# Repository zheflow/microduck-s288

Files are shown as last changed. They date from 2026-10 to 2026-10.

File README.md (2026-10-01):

# microduck-s288

[English](README_EN.md) · 中文

用宇树 **S288** 舵机复刻 Pollen Robotics 的开源双足小鸭 [Microduck](https://github.com/pollen-robotics/microduck)。

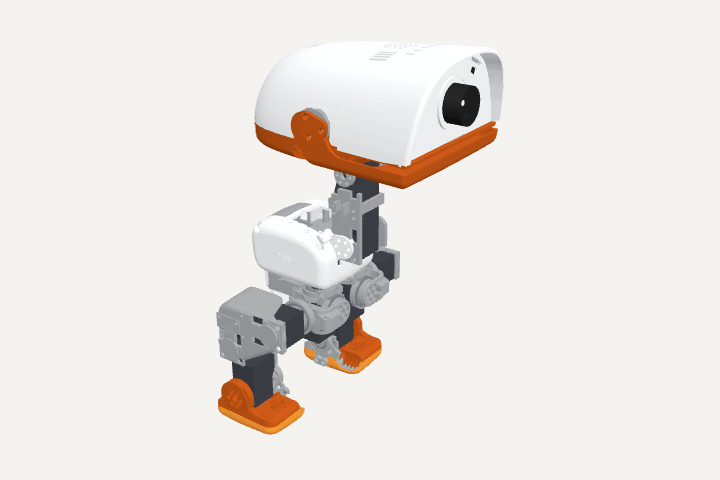
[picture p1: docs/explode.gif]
零件爆炸：散开 / 聚合


<sub>打印件 · 舵机 · 轴承，按子总成散开再聚合。交互版（可拖动旋转）：[docs/explode.html](docs/explode.html)，下载后用浏览器打开。</sub>

> **状态（2026-10-01）：打印件已发打印店，整机还没装起来。** 本次把 **CAD 生成源码、Gate 检查体系和全部设计数据**放出来了（见下"仓库目录"）。
> Gate 还没全绿：剩下的红主要是等实物才能登记的项（起子杆长、坐面、元件质量）和原版同类的碰撞对。
> **请先不要按现在的内容去打印或采购**，STL、清单、装配顺序等整机装起来能站住后再上传（见"路线"）。

---

## 为什么要复刻

原版 Microduck 的仿真模型、训练代码和策略都开源了，但 **CAD 不公开**，用的 Dynamixel XL330 舵机在国内也不好买。
所以这个项目：

- **借**原版的仿真骨架与策略：14 条关节轴线一根不动，原版训练好的走路 / 起立 / 坐站策略作为能力基线；
- **重做**全部结构件：按宇树 S288（塑料齿、塑料壳、Ø10.5 分度圆、实测堵转 0.66 N·m）重新画可打印的结构，
  头壳、髋、偏航件、躯干壳等件在原版网格的毛坯上切削改造；头为了装下主控、摄像头和喇叭每侧放大了 10 mm；
- **重训**：结构和电机都变了，策略要在按我们 CAD 生成的仿真模型上重新训练，不迁就原版限位。

## 选型（已定案）

| 部件 | 型号 | 备注 |
|---|---|---|
| 舵机 | 宇树 S288 × 15 | 含嘴；总线 1 进 5 个一分二，分 6 条串联链；插座在背面两角、沿轴向背插（实物核过） |
| 主控 | Radxa ZERO 3W | 装在头里；摄像头、NPU、USB 直连已在板上跑通 |
| IMU | Adafruit 4438（LSM6DSOX，STEMMA QT） | 躯干前壁，I²C |
| 摄像头 | Radxa Camera 8M 219（IMX219） | 脸板 |
| 测距 | VL53L5CX 多区 ToF | 脸板，避障用 |
| 电池 | 3S 1100 mAh 30C，XT30 | 躯干后仓，后门推入；不用时拔插头 |
| 供电 | 12 V 直供舵机总线；UBEC 5 V/3 A 给主控 | |
| 材料 | PLA 为主；发热处（头支架、头壳、功放 / 转接板托板）PETG；脚底 TPU | |

## 仓库目录

```
docs/explode.gif, docs/explode.html   零件爆炸动画（首页那张）与交互版
docs/gate/                            Gate 体系的校验记录与独立审计
duckstructure/                        整鸭 CAD 参数化生成（Python：trimesh + manifold），按身体部位分文件；data/ 是让位区域网格与头放大缓存
tools/cad/                            装配 / 机械审计、孔与清理检查等（build 和 Gate 共用）
tools/gate/                           Gate 8 层检查：gate.py 入口、layers/ 各层、data/ 设计数据 yaml、negatives/ 反例回归、slicing/ 切片检查
tools/sim/                            MJCF 生成、原版策略真实姿态采样、运动守卫
scripts/fetch_upstream.sh             拉取 Pollen 上游仓库到 upstream/（本仓库不分发它们的文件）
requirements.txt                      依赖版本
```

**Gate 的八层**：L0 网格合法性 → L1 可打印性（真切片）→ L2 特征是否真的切出来 → L3 零位干涉 → L4 装配路径与起子可达 →
L5 螺丝咬入与坐面 → L6 全行程与真实姿态碰撞 → L7 质量与扭矩。每层的判据只写不变量，红绿逐条留证据和出处；
`negatives/` 是反例包，每条判据都有"故意做坏的件必须变红"的回归，改判据先过反例。细节见 [tools/gate/README.md](tools/gate/README.md)。

### 怎么跑

```bash
python3 -m venv .venv && .venv/bin/pip install -r requirements.txt
scripts/fetch_upstream.sh                      # 上游仿真骨架与策略
.venv/bin/python -m duckstructure.build        # 生成 cad/duck_s288/（含 placed/ 装配位网格；十几分钟，吃内存）
.venv/bin/python tools/gate/gate.py            # 全量 Gate，结果在 tools/gate/out/（反例包约 7 min，各层另计）
```

L1 真切片要本机装 PrusaSlicer（`tools/gate/slicing/slice_l1.py --exe` 指定路径），没装时该层标 unknown，不冒充绿。

## 现在到哪一步了

- **CAD**：37 种 / 46 件打印件，全部参数化生成，改一个尺寸整鸭重出；第 8 版打印包已发打印店（左脚先试打）。
- **Gate**：全链能跑通，当前仍有数百条红——多数是"等实物才能填"的登记项（起子杆长、坐面、元件实测质量）和原版同类的碰撞对，
  每条都在 scorecard 里带出处。
- **仿真 / 训练**：按我们 CAD 重生成 MuJoCo 模型；走路 / 起立 / 坐站三个策略已在仿真里训过一轮；头比训练时重，正在做重量极限测试。
- **实物**：舵机、主控、摄像头、IMU、电池到手；主控板烧卡、联网、摄像头、NPU 推理跑通；板端运行时只做到读传感器，还没上力；**整机未装**。

## 路线（上传节奏跟着这个走）

1. ☑ 说明 + 许可证
2. ☑ CAD 源码、Gate 体系与设计数据（本次；Gate 全绿和独立复审在实物装起来的过程中补齐）
3. ☐ 打印件实物装机、能站住 → 上传 STL、打印清单、采购清单、装配顺序
4. ☐ 策略重训完成、实物能走 → 上传仿真场景、权重、训练配置
5. ☐ 主控端运行时（IMU、总线驱动、策略推理）

## 许可证

- **代码**（`duckstructure/*.py`、`tools/`、`scripts/`）：[Apache License 2.0](LICENSE)
- **硬件 / 3D 模型与设计数据**（`duckstructure/data/`、`tools/gate/data/`、`docs/` 里的网格与渲染）：[CC BY-NC-SA 4.0](LICENSE-HARDWARE.md) ——
  原版模型是 CC BY-SA-NC，我们的件是它的衍生作品，**不得商用**，再分发须署名 Pollen Robotics。
- 来源与致谢见 [NOTICE.md](NOTICE.md)。宇树 S288 手册受版权保护，本仓库不分发。

## 联系

Issue 区。项目还在早期，欢迎提问，但请理解"还不能装"这个前提。

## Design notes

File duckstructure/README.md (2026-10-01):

# duckstructure —— S288 版 Microduck 整鸭 CAD（按身体部位组织）

原来的 `tools/cad/duck.py`（1122 行单文件）按身体部位拆成了这个包。**纯搬运重构**：几何、常量、阈值、采样数、注释一字未改，
拆前/拆后 17 个 STL 的 sha256 完全一致、两个 json 去掉时间字段后相同、退出码相同。`tools/cad/s288.py`、`tools/cad/duck_kin.py` 也搬了进来
（`s288.py` 原样，`duck_kin.py` 改名 `kin.py`）。

## 怎么跑

```bash
# 在仓库根目录；一次只跑一个（4~6 分钟、吃内存）
./.venv/bin/python -m duckstructure.build
```

等价于原来的 `python tools/cad/duck.py`：导出 17 个 STL 到 `cad/duck_s288/`，跑零位干涉 + 逐关节扫掠 + 装配/机械审计，
写 `audit_summary.json` / `mechanical_audit.json`，`local/ placed/ scene_*/ xx/` 一并重出；有干涉或未闭环接口时退出码 **2**（当前预期就是 2）。

快速子集检查仍是 `./.venv/bin/python tools/cad/qcheck.py head|trunk|all`，装配抽出检查 `tools/cad/asmcheck.py`。

```python
import duckstructure as D          # 所有公开名字都从包顶层可拿：D.P / D.sfw / D.build_trunk / D.run_checks …
D.PARTS                            # 件号 → (STL 文件名, 导出用 MJCF 连杆, build 函数)，顺序 = 导出顺序
meshes = D.build_all()             # {件号: 世界坐标网格}，只建不导出不检查
```

## 改几何只改这里

| 想改什么 | 改哪 |
|---|---|
| 舵机尺寸（标 `[量]` 的实测值） | `s288.py` 里的 `S` |
| 关节轴线 / 舵机位姿 | **不要改** —— `kin.py` 从 `upstream/microduck_rl/.../robot_walk.xml` 读，是训练好的策略骨架 |
| 参数表 `P`、轴承/背板/踝副轴常量、电池仓位置（`BX0/BX1/BZ0/BZ1/RAIL_Y…`）、壳安装柱 `SHELL_BOSS`、`SERVO_SHIFT` | `lib.py` 顶部（冻结项，动之前先看 `docs/`） |
| 某一个件的形状 | 对应部位模块里的 `build_*`（下表） |
| 检查阈值 / 扫掠范围 `SWEEP` / 旧检查域 `LEGACY_LIMITS` | `checks.py` |
| 导出顺序、哪些原版件参检、场景导出 | `build.py` |

## 17 件一览

| 件号 | STL | build 函数 | 模块 | 装什么 | 依赖哪些别的件 |
|---|---|---|---|---|---|
| L01 | `L01_yaw2roll.stl` | `build_yaw2roll()` | legs | 髋偏航从动盘 + 髋横滚舵机载体（照原版 yaw2roll 重雕） | L02（左右髋件绕横滚/偏航轴扫掠让位） |
| L02 | `L02_hip.stl` | `build_hip()` @memo | legs | 纯双从动盘：一面髋横滚、一面髋俯仰 | — |
| L03 | `L03_upper_leg.stl` | `build_upper_leg()` @memo | legs | 大腿：髋俯仰 + 膝两颗舵机的等厚背板 + 膝 6704 座 | — |
| L04 | `L04_lower_leg.stl` | `build_lower_leg()` @memo | legs | 小腿：膝从动盘 + 踝舵机背板 + Ø9.95 踝副轴颈 | L03（膝反向扫掠）、电池实体（髋偏航扫掠） |
| L05 | `L05_ankle_foot.stl` | `build_ankle_foot()[0]` ← `build_ankle_parts()` @memo | legs | 踝主脚（法兰侧从动盘 + 脚板） | L04（踝反向扫掠 ±`ANK_SWEEP`）；`tools/cad/ankle_split.py` 分体 |
| L06 | `L06_sole_TPU.stl` | `build_ankle_foot()[1]` | legs | TPU 鞋底（原版 sole 减去 L05/L07） | L05/L07 |
| L07 | `L07_ankle_rear_arm.stl` | `build_ankle_rear_arm()` | legs | 可拆后轴承臂（6700ZZ 座，M2×12 接 L05） | 同 L05 |
| T01 | `T01_trunk.stl` | `build_trunk()` | trunk | 躯干：两个髋偏航载体 + 顶板 + 颈俯仰轭 + 电池仓 + 原版腹面甲板 + 壳柱 | 原版 left/right_shell（当刀）；`battery_bay()` |
| B01 | `B01_battery_door.stl` | `build_battery_door()` | trunk | 电池仓门（底脚 + 卡珠槽 + 2×M2） | — |
| T02 | `T02_shell_L.stl` | `build_trunk_shell(+1, trunk)` | trunk | 左躯干壳（原版外形，挖脖子活动空间 + 2 个 Ø2.4 孔） | T01（颈部区让位）、N01+N02（`neck_swing_env`） |
| T03 | `T03_shell_R.stl` | `build_trunk_shell(-1, trunk)` | trunk | 右躯干壳 | 同 T02 |
| N01 | `N01_neck.stl` | `build_neck()` @memo | neck | 脖子：颈俯仰 + 头俯仰两颗舵机背靠背的载体 | N02（头俯仰 ±45° 扫掠） |
| N02 | `N02_neck_pitch.stl` | `build_neck_pitch()` @memo | neck | 颈俯仰件（U 形轭 + 偏航立筒，照原版重雕） | — |
| N03 | `N03_yaw_roll.stl` | `build_yrm()` | neck | 偏航-横滚件（A/B 座盘 + 等厚背板 + 裙墙） | — |
| H01 | `H01_head_bracket.stl` | `build_head_bracket()` | head | 头内支架（原版 motor_support 毛坯 + 横滚舵机笼 + 香橙派立柱） | N03（横滚 ±25° 扫掠） |
| H02 | `H02_head_clamp.stl` | `build_head_clamp()` | head | 可拆压板（两根垫柱压横滚舵机背孔，两颗 M2×10 接 H01） | — |
| H03 | `H03_head_bottom_shell.stl` | `build_head_bottom_shell()` | head | 原版下头壳的 S288 适配件（只挖舵机让位） | — |

右腿 5 件不单独建：`build.py` 用 `mirror_y()` 镜像左腿参检（`MIRROR` 表给出镜像后的 MJCF 连杆名）。

`@memo`（`lib.py`）：同一进程内同名 build 函数只算一次，结果放在 `lib._MEMO`。L01 里扫 L02、L04 里扫 L03、L05 里扫 L04、
N01 里扫 N02、T02/T03 里建 N01/N02 都走这个缓存，所以谁先建都不会重复算。

## 模块与依赖

```
s288 ───┐
kin  ───┼──▶ lib ──┬──▶ legs ──────────────────────┐
                   ├──▶ neck ──┬──▶ trunk ─────────┤
                   │           └──▶ head ──────────┼──▶ build（入口）
                   └──▶ checks ────────────────────┘
                                   __init__ 再导出以上全部公开名字，给 build.py / tools/cad 的检查脚本当"duck 模块"用
```

| 模块 | 放什么 | 行数 |
|---|---|---|
| `s288.py` | S288 舵机参数表 `S` 与舵机坐标系原语（`cyl/bx/union/diff/inter/placed/frame/servo_envelope/servo_mesh/horn_holes/mount_holes…`） | 166 |
| `kin.py` | 读 MJCF `robot_walk.xml`：`load()` → `B, ORDER`（连杆树、关节、舵机位姿、原版网格）；`mesh(name)` | 62 |
| `lib.py` | `OUT`、`B/ORDER`、参数表 `P`、全部全局常量（`XR/PLT/RING_T/ANK_*/电池仓/RINGS/SHELL_*/SERVO_SHIFT/XLF`）、`memo`、世界/舵机坐标工具（`TW/orig/sfw/drv_from/drv_self/pt/servo_env/to_local/mirror_y/MIRROR`）、舵机坐标原语（`carrier/spacer_card/card_cut/mount_cut/driven/driven_patch/horn_cut/horn_cbore/flange_relief/flange_slot/mnt_cut2/back_pad/back_shell/wide_y/brg_ring/ring_boss/bearing_driven_clearance/servo_slide`）、通用几何（`hull/wbox/ybox/fill_cyl/silhouette/sweep_of/keep_main/minkowski_box/clean_print_topology/stl_stats`）、原版壳（`shell/shell_inner_z/shell_cutter`） | 448 |
| `legs.py` | L01–L07 | 124 |
| `neck.py` | N01–N03 及其局部常量（`NK_*/NP_*/YRM_*`） | 132 |
| `trunk.py` | 电池仓（`battery_bay/battery_bay_cuts`，仓门/底脚/卡珠常量 `FOOT_*/DOOR_SCREW_X/SNAP_*`）、B01、`DECK_TOP`、T01、`neck_swing_env`、T02/T03 | 158 |
| `head.py` | `HEAD_CLAMP_MOUNTS`、H01–H03 | 88 |
| `checks.py` | `check_angles`、`EXPORT_STATS/export`（STL 闭合/单实体断言）、`vol`、`descendants`、`LEGACY_LIMITS`、`SWEEP`、`run_checks`（零位干涉 + 逐关节扫掠） | 109 |
| `__init__.py` | 再导出各子模块的公开名字、`PARTS`（件号→build 函数的有序表）、`build_all()`；把 `tools/cad/` 塞进 `sys.path` | 57 |
| `build.py` | 原 `duck.py` 的 `__main__` 原样：建 17 件 → 镜像右腿 → 原版头壳/舵机/轴承参检 → `run_checks` → `mechanical_audit.verify_mechanics` → 写两个 json → `local/ scene_*/ placed/ assembly_preview.stl` → `sys.exit(2)` | 111 |

归属原则：被谁用就放谁那，多处共用放 `lib.py`。和"部位"直觉不一致的几处：

- **电池仓位置常量**（`BAT_CLR/BX0/BX1/BZ0/BZ1/BAT_Y/RAIL_Y/RAIL_Z0/DOOR_*/BAY_FW/BRACE_Z/BZR0/BZR1`）在 `lib.py` 而不是 `trunk.py`：
  L04 小腿要拿电池实体绕髋偏航扫掠削让位，`build.py`/`qcheck.py` 也要放电池实体参检。仓门自己的常量（`FOOT_*/DOOR_SCREW_X/SNAP_*`）留在 `trunk.py`。
- `neck_swing_env()` 在 `trunk.py`：它建的是脖子的扫掠包络，但只有躯干壳用它挖料。
- `ybox()`、`mirror_y()/to_local()/MIRROR` 在 `lib.py`：L01 要镜像对侧髋件，`build.py`/`qcheck.py` 要镜像整条右腿。
- `check_angles()` 只被 `run_checks` 用，放 `checks.py`。

## 与 tools/cad/ 检查脚本的关系

`tools/cad/{assembly_audit,mechanical_audit,ankle_split,asmcheck,qcheck}.py` 留在原地，改成从 `duckstructure` 导入。
`assembly_audit.bearing_specs(D)` / `mechanical_audit.verify_mechanics(D, allm)` 需要一个带 `B/sfw/TW/cyl/vol/placed/s288/orig/inter/diff/…` 属性的"duck 模块"，
`build.py` 传的是 `duckstructure` 包本身（原来是 `sys.modules[__name__]`）。

包里保留了原文的三处**函数内延迟 import**（`lib.minkowski_box/clean_print_topology` → `assembly_audit.solid`，`legs.build_ankle_parts` → `ankle_split.split_ankle`），
它们 import 的是 `tools/cad/` 的顶层模块而不是包内模块，本身没有循环；`__init__.py` 把 `tools/cad/` 塞进 `sys.path`（原 `duck.py` 第 7 行的等价物）。
包内模块之间没有循环依赖，模块划分本身就是无环的 —— 没有任何一处包内依赖是靠函数内 import 掩盖的（上面三处延迟 import 指向的都是包外的 `tools/cad/` 脚本，原文就这么写）。

## 拆分时唯一改过的三处（都不是几何）

1. `lib.py`：`OUT = …("..", "cad", "duck_s288")`——原来是 `("..", "..", …)`，因为文件从 `tools/cad/` 上移了一层。`kin.py` 里 `MD` 同理少一个 `".."`。
2. `build.py`：`bearing_specs(sys.modules[__name__])` → `bearing_specs(D)`；`verify_mechanics(sys.modules[__name__], allm)` → `verify_mechanics(D, allm)`，`D` 即 `duckstructure` 包。

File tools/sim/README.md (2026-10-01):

# 本地策略回放的 CAD 预检

`render_policy.py` 现在在写入 `data.ctrl` 前执行强制预检。预检拒绝时退出 **2**，保留 JSON 中的关节、姿态、路径比例、相交零件和 mm³；不会把目标逐轴夹角后继续运行，也没有跳过预检的命令行选项。

从仓库根目录用 `./.venv/bin/python`：

```sh
# 仅在完整 CAD 构建结束、STL 稳定后记录源身份。这个操作不表示几何通过。
./.venv/bin/python tools/sim/cad_motion_check.py snapshot

# 真实回放入口，所有输出检查在本机执行，不打开串口。
./.venv/bin/python tools/sim/render_policy.py \
  sim/runs/2026-09-06_baseline_xl330/baseline_xl330.onnx \
  sim/guarded_policy.mp4 --seconds 5 --no-video \
  --report docs/repair_2026-09-09/motion/replay_preflight.json

# 也可以先检查已记录的目标序列；遇到第一处问题停止。
./.venv/bin/python tools/sim/cad_motion_check.py trajectory \
  docs/six_checks_2026-09-08/policy/forward.npz \
  --report docs/repair_2026-09-09/motion/forward_preflight.json

# 轻量回归，不创建真实 CAD、不操作硬件。
./.venv/bin/python -m unittest discover -s tools/sim -p test_motion_guard.py -v
```

实际生效的检查：

- 关节顺序和全部 14 个关节范围直接读 `robot_walk.xml`；不使用旧 CAD 窄窗口。目标、当前姿态和上次目标必须全维、有限且符合范围。右髋横滚的 23.093° 目标会被拒绝，MJCF 上限为 22°。
- 用 `placed` 世界零位网格和完整运动学链做联合姿态布尔检查，阈值保持 **0.05 mm³**。该阈值只是数值检查阈值，不是可以接受的物理干涉。
- 每次提交检查“当前姿态→目标”和“上次目标→新目标”两条关节线性过渡；最大单关节采样间距 **0.5°**，短移动也检查中点。每个 MuJoCo 物理步后还检查观测姿态间过渡，发现偏离造成的冲突则停止后续积分。
- 固定在同一刚体内的适配件也在启动时检查。剩余三个原版头部原件之间的 3 个配对沿用主 CAD 明示排除范围。H03只对上头壳保留一个额外白名单：每次加载都从原版下头壳计算原始交集，确认 H03 的交集没有超出原始接合区（数值误差阈值0.001 mm³）。H03与舵机、支架、脸件和下颚等其他配对正常检查；白名单与原版对比数字写入报告。
- `cad_geometry_manifest.json` 绑定完整对象清单及 STL、运动学和相关源码的 SHA256。缺件、多件、源散列不符、运行中源文件改动、布尔异常或无效结果均拒绝。运行时检查文件的 inode、大小、mtime、ctime；重新启动时完整核对散列。缓存不能绕过源变化检查。

`MotionGuard.apply_target()` 是可复用入口，但它只实现离线的预检。回放明确选用 **scene_walk.xml→robot_walk.xml**，与六项补查的基线一致；原入口所用的 `scene.xml→robot_allcollisions.xml` 不再被间接默认选择。物理步长0.005 s、implicitfast、10次接触求解迭代都写入报告。它仍是 **原 XL330 XML 执行器动力学**，没有添加 S288 整机驱动，也没有声称已接入实机。拒绝意味着停止离线回放，不能把这个处理直接移植成运动中的实机急停策略。

采样通过仅证明已取样姿态没有超过阈值的相交：它不证明连续时间无碰撞、任意执行器异步响应安全、制动可行、打印公差、轴承负载、线束或电路安全。模型有固定干涉时，正确行为是启动即拦截；源身份快照不是绕过这个拦截的许可。

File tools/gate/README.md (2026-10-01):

# Gate —— 可打印 / 可装配评价体系（规格）

> 目标：**换件（摄像头、麦克风、头壳……）之后不改检查器，还能查对。**
> 做法：检查规则只写**不变量**，不含任何具体零件的具体坐标；一切"应该是什么"都在 `data/` 里声明，换件只改数据。

状态：规格阶段。元件库与三份清单正在从原版 + V2 盘点生成（见 `docs/gate/inventory_*.{json,md}`）。

---

## 1. 数据（`tools/gate/data/`）—— 换件只改这里

| 文件 | 内容 | 一条记录长什么样 |
|---|---|---|
| `components.yaml` | **元件库**：每个外购件一条 | envelope / mount 孔阵 / connectors(位置·插头实体·拔插方向·线出口) / cable(根数·径·最小弯折半径·长度) / keepout(视锥·声孔·气路) / mass·com / power·heat / insert_dir / **每个字段标 measured\|datasheet\|assumed** |
| `parts.yaml` | 17 个打印件 | 由哪个 build 函数出、材料、打印朝向、镜像关系、houses(装了哪些元件) |
| `features.yaml` | **特征清单** | 每个孔/沉头/槽/凸台/夹持面：件、种类、名义尺寸、深度、通盲、方向、作用（固定谁）、连接类型 |
| `fasteners.yaml` | 每颗螺丝 | 规格、长度、连什么和什么、拧进什么材料、**它自己的刀具包络**（Ø4/Ø5/PH0…）、驱动方向 |
| `assembly.yaml` | **装配顺序清单** | 逐步：动哪个件、沿什么方向/路径、此时已装了什么、用什么工具；拆卸序也写 |
| `relations.yaml` | **功能关系清单** | 夹持/压配/滑配/轴承座/舵盘耦合/从动盘/铰链：谁和谁、目标量（过盈·间隙·同心）、依据（实测试件 or 占位） |
| `keepouts.yaml` | 禁入体 | 视锥、声孔、舵盘摆动扇区、电池抽出路径、SD/USB/开关/充电口、刀路、线束弯折空间 |
| `harness.yaml` | 线束路径 | 每束：折线 + 直径 + 最小弯折半径 + 两端插头 + 长度预算 + 跨哪个关节 |
| `frozen.yaml` | 不许动的 + **能力包络** | 关节轴线、电池仓 26 项、SHELL_BOSS、立柱、6 个原版 STL、**躯干 IMU 位姿**；`capability_envelope`（2026-09-16）：原版策略在 in-scope 任务模式下实际用到的关节角（来源 policy_envelope.json、左右镜像求并、margin），`joint_axes[].target_range_deg` 由 `derive_target_ranges.py` 从它推导——**判据来自原版能力，件去满足它**，不按件能转多少填 |
| `tolerances.yaml` | 公差表 | 按 **材料 × 打印方向 × 特征类型** 存；未实测的填占位值并标 `assumed`。**连接类型决定咬入范围**：S288 金属螺纹 1.8~3.0 / PLA 自攻 ≥2×d / 热熔螺母按螺母长 |
| `waivers.yaml` | 豁免 | 格子 id、理由、签发人、日期、**绑定的输入 hash**（输入一变自动失效） |
| `bench.yaml` | 实机验证清单 | 只能实测的判据（预紧变形、温升、掉线行为、疲劳…），现在写死数字，到货逐项打勾 |

---

## 2. 层（每层一句话判据，全部 mm / mm³，不四舍五入，未知 = 失败）

| 层 | 问 | 判据 | 数据来源 |
|---|---|---|---|
| **0 网格与坐标** | 是合法实体、在对的坐标系里吗 | 洞边=0 · 实体=1 · 退化面=0 · 非流形边=0 · **基准特征（舵盘轴心）落在 MJCF 位置 ±0.05** · 包围盒在预期范围（抓米/毫米、Y-up、未 apply transform） | parts / frozen |
| **1 可打印** | 打印机吐得出来吗 | 真切片：最薄壁 ≥2 圈 · 最小孔 ≥2×喷嘴 · 悬垂 >55° 的面在支撑可拆区 · **支撑落点按真 G-code**：forbid 区（轴承座/轴颈/锪平/走廊配合面壳层）= 0 点 BLOCK、removable 区 WARN + 后处理 · TPU 单独规则 | parts(朝向·材料) + printability(parts/no_support_zones) + tolerances |
| **2 特征存在** | 声明的孔/台/槽真的在吗 | 逐条：射线验通/盲深 ±0.1 · 直径 ±0.1 · 沉头 · 孔周壁厚 ≥ 阈值 · **镜像件特征镜像误差 <0.05** | features |
| **3 静态装配** | 零位姿各就各位吗 | 打印件 × 打印件、打印件 × **元件完整实体**（placed 占位体 + `envelope_solid` 独立实体两份）、× **禁入体**（几何/豁免全在 keepouts.yaml，KO01 不借 CAD 切刀）：交集 < 0.05 mm³ · **冻结项实测**（电池仓 26 项 / H01 立柱 / IMU 安装孔 ±0.1） | components / keepouts / frozen / fasteners ；**hr50（09-28）**：`frozen.yaml:battery_bay_26.door_plate_retired{probes,date,decided_by,regression_now}` 列出的门板侧探针（DOOR_T / BX0 / DOOR_YLO…）照量照记数字但发 RETIRED（用户 09-22 解冻电池仓+门、hr48 有意改门；回归转 L2 B01-F01）；非门板探针名 / 缺字段 → unknown 且不退役 |
| **4 装得进去** | 每个东西有路进到位吗 | 按 assembly.yaml 逐步：移动件沿路径扫掠 vs 已装件 = 0 · 每颗螺丝按**自己的**刀具包络有直线通道 · 螺丝头沿刀轴可见 · 拆序也通 | assembly / fasteners |
| **5 功能达成** | 装上后它干活吗 | 夹持过盈 · 卡扣咬合深 · **咬入按连接类型** · 螺丝总长 ≤ 叠厚+盲深−0.3 · 轴承配合按公差表 · 舵盘 6 孔同心 <0.05 · **舵盘时钟**（零位下孔阵相位 = 声明值，抓 60° 倍数错位）| relations / fasteners / tolerances |
| **6 运动** | 动起来撞不撞卡不卡、**原版能做的姿态我们做不做得出** | 单轴 2.5° 独立网格 + **相邻关节两两组合 5° 统一网格**；碰撞在 `frozen.yaml:target_range_deg`（由能力包络推导）内 BLOCK、外 WARN（工作空间比原版窄但原版任务用不到）；**能力判据** `_capability/*`：每个 in-scope mode 的包络 ± margin ⊆ 本层量出的无碰撞区间（BLOCK）、**原版策略真实姿态**（`policy_envelope.py --dump-steps` 逐步元组 → `policy_pose_collisions.py` 离线布尔 → `policy_pose_compare.py` 与原版全件同姿态逐 body 对比，summary/compare 双指纹核对）**hr50（09-28 用户定：极限姿势靠重训限制、不削）起按 `tools/gate/data/real_pose_policy.yaml` 判**：极限段（alpha_stand/body_all_max、roulade、alpha_sitstand/head_all_min）里的碰撞不阻断，逐对列进 `real_pose_retrain_constraints`（INFO：件对、姿态数、最大交集、最大那帧穿插深度、到头的关节）；其余姿态交集 ≤2.2868 mm³ 且穿插深度 ≤0.7696 mm（原版自身真接触峰值 p25，hr50 C 标定）为轻碰，超出或深度算不出 → `real_pose_collisions` BLOCK；原版共有碰撞仍不豁免；**相邻两关节组合 `pair_combination`（hr50 v3，09-28 用户定，同一 yaml 的 `pair_combination` 段）**：碰撞记录逐条分类 —— 有一轴在目标区间外 → 工作空间 WARN（F-L6-3 不变）；区间内、网格姿态 ±5.5°（网格半步 2.5 + margin_deg 3）内原版策略逐步记录（`frozen.yaml:capability_envelope.pose_steps_source`，sha 校验，去掉三段极限段，按 mirror_pairs 左右镜像求并）从没到过 → 进 `pair_combination_retrain_constraints`（INFO：件对、最大交集、深度、撞点网格按连通块给耦合区间『q1、q2 不能同时进这个区间』，各向外扩一格）；到过 → 同上轻碰口径，超出 / 深度算不出 BLOCK；**v4（09-28 用户定）**：超轻碰但落在 `approved_retrain_constraints`（用户逐条批准的重训联动限位：件对 × 关节对 × 耦合盒 × 体积上限，上限 = 正式 chain 在冻结 STL 上量的数、不留余量）盒内且 ≤ 上限 → 不 FAIL、逐条列出，超上限 / 盒外照 BLOCK，登记了没命中的列 unused；重训约束另按关节对合并成训练用区间（`per_joint_pair`）；**v6（09-28 用户定 C）**：`_policy/policy_extreme_poses` 的策略包络角点姿态记录（每 mode 30 个 14 轴同时到包络角的姿态，不是可达集）也按同一口径逐条分类（『到过』= **全部 14 轴**同时 ±5.5° 内有原版样本），没到过 → `_policy/policy_extreme_poses_retrain_constraints`（INFO），只有『到过且超轻碰』BLOCK、只有区间外 WARN；件格子 / 汇总按 `pose_class` 同分类；口径段缺 → unknown；同一批记录在 `motion_collision` / `collision_buckets` 里也按这个分类，只有『到过且超轻碰』算件的问题；包络证据坏 / 分类失败 → unknown；能力盒内的碰撞只 WARN（轴对齐盒是上界，README A2）；生成 MJCF range ⊆ 无碰撞区间、⊇ 目标区间；运动对**最小距离 ≥ 公差表值**（豁免只认 relations 声明的 contact）；线束沿路径扫管过全行程 | frozen(capability_envelope, target_range_deg) / policy_envelope.json / relations(contact) / harness / tolerances |
| **7 质量与力** | 撑得住、站得稳吗 | 17 件体积×密度 + 元件实重（按 `components.yaml:claim` 认领）→ 每 body 质量重心 · **与 MJCF `<inertial>` 逐 body 比漂移** · 每关节扫描峰值与 home 姿态静扭矩 < S288 额定 × 系数 · 零位/home 重心投影在支撑多边形内 · **质量清单有缺口 → 整机判据 unknown（只给下界文本）** · 承力最小截面 / 薄筋长厚比 / 层向 vs 受力 | components(mass, claim) / parts(ground_contact) / frozen / tolerances(load) |

不进 Gate、进 `bench.yaml` 的：预紧变形与摩擦、多舵机峰值电流与压降、温升、掉线/重上电行为、线束疲劳、热管理、传感器实际可用性、耐久。

---

## 3. 元规则（保证"绿"是真绿）

1. **查最终导出的 STL 读回来的东西**，不查内存网格。送去打印的是文件。
2. **每个 0 带证据数量**：几对、几个角度、几条射线。`0 碰撞 / 0 对` = 没跑，不是通过。
3. **采样网格独立于建模角度**（`check_angles()`）。
4. **未知 = 失败**：布尔炸了、特征找不到、清单没写、字段是 `assumed` 而配合间隙 < 公差表值 → 都红。
5. **不变量，不比历史**：体积/交集与上一版的差异只做 WARN 级"变更告警"触发人看，**不是放行条件**。
6. **hash 绑定**：记分卡写入 `duck.py`、`s288.py`、`robot_walk.xml` 的 git hash + 17 个 STL 的 sha256 + `data/*.yaml` 的 sha256。hash 对不上的记分卡作废；发布副本 ≠ 源码直接红。
7. **过期标记**：每个格子记录输入 hash；输入变了格子变灰，不得沿用旧绿。改一个件只重跑受影响子集。
8. **反例回归包先跑**：`negatives/` 里每个历史事故一个坏样本（空刀、轴承截面、压板零间隙、扫掠区间反、螺丝加长 2 mm、删一个件、单位错成米…）。Gate 每次运行先证明自己**每个都能红**，否则 Gate 本身判失败。
9. **三级 + 豁免**：BLOCK / WARN / INFO。只有 WARN 可豁免，豁免绑定输入 hash，输入一变自动失效。
10. **性能**：内容 hash 缓存 · AABB / 采样距离粗筛后再精确布尔 · 单件检查可独立跑；整机全绿一次不应超过现在 `duck.py` 的一半时间。

### 3.1 元规则落地状态（2026-09-13 审计后第一批；每条修复都有反例）

| # | 状态 | 落在哪 | 反例 |
|---|---|---|---|
| 1 | 落实 | 各层读 `cad/duck_s288/*.stl` / `placed/*.stl` | n_l0_units_meters / n_l2_* |
| 2 | 落实 | `core.build_scorecard`：evidence_n=0 的 PASS → NOT_RUN | n_core_evidence |
| 3 | 落实 | `duckstructure/checks.py:check_angles` 零度对齐网格 | n_l6_reversed_range |
| 4 | 落实（框架级补丁） | 覆盖率义务在清单缺 id 时**写红格**而不是跳过（`core.py:COVERAGE_ITEMS` 循环） | n_core_coverage_no_id |
| 5 | 落实 | 层不读 prev；`impact.md` 只报变化 | — |
| 6 | 落实 | `gate.py --verify`：逐格 inputs_hash + source_manifest + git HEAD 与磁盘核对，不一致退出码 3 | n_core_verify |
| 7 | 落实 | 格级 inputs 隐含 `duckstructure/*.py`；`--layers/--parts` 子集跑写 `scorecard.partial.json`、不写 prev，范围外格子按 hash 继承 | n_core_partial_inherit |
| 8 | 落实（契约收紧） | 反例必须声明 `expect_severity` 且 `red` 里每条 measured 非 None（`negatives/runner.py:check_contract`）；结果按 `sha256(negatives+layers+core+gate+tool_access+slice_l1+data)` 缓存到 `out/negatives.cache.json` | 全部 n_* |
| 9 | 落实 | 豁免 id 必须带判据名；`bound_input_hashes` = {仓库相对路径: sha256}（`waivers.yaml:schema`） | n_core_waiver / n_core_waiver_cell_only |
| 10 | 部分 | 反例缓存命中 ≈ 0.03 s；层级结果缓存仍未做（全跑 ≈ 30 min；09-13 第二批后 L6 组合 5° 网格多 ≈5 min） | — |
| 4b | 落实（L5/L7） | **阈值也要有来源**：`fits.*.target_range_*` / `feature_check_tolerances.*` / L7 密度·稳定裕度·筋容差 节点无 `src` → 引用它的判据 unknown；`src=assumed` → 照判 + `threshold_assumed:<键>` FAIL(WARN)，measured=阈值本身（`l5_screwhead.threshold_meta / AssumedThresholds`，l5_function、l7_mass 同源） | n_l5_threshold_src、n_l7_generalized |
| 4c | 落实（gate_guard 09-25） | **层崩溃 / 层空跑不许静默**：层模块抛异常 / 层进程被杀、进程池断 / 返回不可解析 / import 失败 → `L<n>/_layer_error`（FAIL，BLOCK，`layer_crashed`）；全量跑时层模块 0 条判据 → 同格（`layer_zero_findings`），子集跑只打印提示；终端摘要顶部与记分卡 md 标题下各一行 ⚠，结论 BLOCKED、退出码 1（`gate.py:_layer_guard`；断池时 `_exit_after_main` 用 os._exit 收尾防解释器收尾挂死） | n_core_layer_error |
| 8b | 落实 | 反例缓存 key **静态全盖**（`tools/gate/**/*.py`、`duckstructure/*.py`、`tools/cad/*.py`、`data/*.yaml`、`slicing/*.yaml`、`l1_calibration.yaml`、标定网格）+ **运行时** `sys.modules` 仓库内模块清单 + trimesh/manifold3d/numpy/shapely/Python 版本；命中时 `L0/_negatives` 照写、标 `cached` | n_core_neg_cache_key |

状态语义：`STALE` = 输入变了没重跑（继承可恢复）；`RETIRED` = 判据基准失去权威、只留记录（不阻断、不计 INCOMPLETE、单独计数，`core.py:RETIRED`）。层里**不许**再硬编码 `state=STALE`。

### 3.2 本轮新增的写层约束（2026-09-13，各有反例）

| 约束 | 来源 | 反例 |
|---|---|---|
| **覆盖 = 量到，不是发过**：`res.covered` 只登记至少发出一条带 measured 判据的条目；只发 unknown 的不算覆盖 | F-L2-1 | n_l2_coverage_gap |
| **量的是零件不是三角化**：从网格取尺寸必须对分段数免疫（棱边/顶点法），射线内接径只作旁证；float32 表示噪声（≤1e-5）可吸收，阈值不动 | F-L2-2 | n_l2_facet_diameter |
| **"有实测撑着" = 实测通过了**：桶/汇总格只能引用 state==PASS 的实测判据；量了没过要传红，不传"已量" | F-L5-3 | n_l5_fit_measured_only_on_pass |
| **方向必须声明，不取较差端**：头侧、压紧方向只从 data 的显式字段取，取不到判 unknown；"两端取较差"是把对面的缺陷记到这一面 | F-L5-1/2 | n_l5_head_on_pilot_hole、n_l5_fg15 |
| **没评过 ≠ 没误伤**：标定/统计类判据分母只数真评过的（PASS 且 evidence_n=0 不算）；范围内任一 BLOCK 判据一次没评 → 标定不成立 | F-L1-1 | n_l1_calibration_record |
| **"每个"就写 `== len`**：criterion 写"每个"的判据不许用 `if n:` 判 | F-L7-2 | n_l7_inertia_tensor_all |
| **区间必须有序**：任何 [lo, hi] 声明 lo ≥ hi 一律 unknown，不许让采样函数退化成两端点 | N4 | n_l6_reversed_range |
| **反例先跑一次红**：新判据/修复先写反例并在改代码前跑出失败，再改 | 元规则 8 | 本轮全部 |
| L4 工位在场全集必须 ⊇ 从 `seq`/`subassembly_of`/`subassemblies` 推导的最小集合（`present_covers_derived` BLOCK）；反向顺序矛盾 `present_only_installed` WARN；`tool_states` 必须带 `after_step`/`side` | F-L4-1 | n_l4_present_derived |
| L4 轴承 token（6700/6702/6704/`22×16×4`）→ 外径按 `components.yaml` 解析，不写死 | F-L4-1 / §2.6 | n_l4_present_derived（'6704×2' 类 token 进 parts） |
| **禁入体不借 CAD 切刀**：KO01 插头顶/线弯区 A + 侧出线槽 B / 背板通窗 W 由 `keepouts.yaml:KO01.dims` + `availability_table.rows[].mode_*` 独立建（09-20 背插模型），舵机落位只借 `sfw`；CAD `conn_cut` 只作对照 INFO（`keepout_KO01_vs_cad_cutter`）；dims 缺 → unknown | F-L3-2 | n_l3_ko01_independent |
| **元件实体要有一份不与 CAD 同源的**：`components.yaml:envelope_solid`（ring/box/none）独立建实体、落位只借 placed 的 OBB；`placed_covers_envelope`（顶点法，对分段数免疫）+ `part_vs_component_envelope`；同源的 `part_vs_component_solid` criterion 写明"与 CAD 同源"；未声明 → unknown | F-L3-3 | n_l3_component_envelope |
| **冻结项要真核**：`frozen.yaml` 的 `battery_bay_26`（T01/B01 射线）、`h01_sbc_posts`（H01 截面闭环）、`imu_pose`（T01 射线扇 + 生成 MJCF site + delta 算术）按 `measured_on` 对导出件实测，阈值 `frozen_dimension_mm`；射线分不出的（卡珠埋在导轨里）判 unknown，不是导出件几何的逐条 INFO 登记 | F-数-1 | n_l3_frozen_items |
| **禁入体参数与豁免全在数据**：KO06 `servo_frame_of_joint`、KO07 `axis_joint`、KO11 `probe_zone_z_mm`、KO12 `exempt[]`、KO15 `fov_deg/apex_world_mm/optical_axis_world` —— 缺 → unknown，不再默认 `neck_pitch/head_yaw/100..175/"B01"/+x`；元件认领按 `components.yaml:claim`（与 L7 同一份声明） | §2.6（L3） | n_l3_keepout_data_driven |
| **扫掠/运动类禁入体的义务派给真查它的层**：`keepouts.yaml:KOxx.checked_in_layer` + `covered_by_subjects`；`core.obligations` 按它派层，`core.build_scorecard` 把所列格子汇总成 `L{层}/KOxx`（缺格 NOT_RUN、红传红），第 3 层只留 NOT_RUN INFO 留痕 | L3 MINOR（`_DEFERRED` 永久 INCOMPLETE） | n_core_keepout_layer_routing |
| **支撑落点按真 G-code**：解析 `;TYPE:Support material/interface` 挤出段 0.2 mm 采样、逆变换回 export_local、对 `no_support_zone_set` 逐区数点；两级 forbid（BLOCK）/ removable（WARN + 后处理进打印清单）；`per_feature_overrides` 可改级；zones_sha256 只带**本件**特征的 override，别件改 override 不作废本件记录 | F-L1-3 / C-10..13 | n_l1_support_landing_tiers、n_l1_support_in_bore/_box_zone |
| **切片配置不进代码**：逐件朝向 / 填充率 / 周界生成器 / 追加参数全在 `printability.yaml:parts.<件>`（`down_world` 等），缺 → `slice_l1.py` 退出不给缺省；`--parts` 子集重切沿用其余件记录 | §2.6（slice_l1） | —（脚本级，层由 slice_freshness/zones_sha256 兜住） |
| **刀心不是坐面**：`features.yaml:hole_positions_mm` / `feature_hole_map[].holes` 是切刀中点（常离件 15–19 mm 甚至在件外），只能当轴线锚；头/坐面判据的起点一律是 `fasteners.yaml:tool_access[].seats[].point_export_local`，头侧 = `outward_export_local`；坐面点到孔轴横向偏差 > 1e-6 → unknown（与 `tool_access.py` 同规则）；孔轴优先取特征声明轴（`geom.instances[k]` 按 `feature_hole_map[].instance` 取），实测轴起点在孔腔里、只作 `hole_axis_declared_vs_measured` 旁证 | F-L5-2 第二半 | n_l5_seat_origin_cutter_mid、n_l5_fg15（E：坐面点在料里 → unknown） |
| **匹配键带 instance**：`declared_head_sides` 键 = (feature_id, instance, map_index, hole_index)；左右实例（mirror_y，同一份 STL、export_local 同坐标）同 outward 不是冲突、几何量一次并记录覆盖的 instance；"冲突"只在同一 instance 同一孔给了不同 outward 时成立；某个 instance 缺坐面 = 那颗螺丝未声明 → unknown | F-L5-2 第二半 | n_l5_seat_instance_key |
| **头侧孔全集 = `head_locator_map_indices`**：同一颗螺丝的 counterbore / spot_face 条目不是另一颗螺丝，不进"未声明"计数，也不作为叠厚/坐面的测量孔；locators 缺/重复/越界 → `head_side` unknown | 主线程 09-13（F02/F03/F10 "6/12 未声明"真因） | n_l5_seat_instance_key、n_l5_seat_origin_cutter_mid |
| **头判据只看头高区**：从坐面点沿 outward 退 60 mm 向内打，每条射线只认坐面外侧 ≤ 头高（`frozen.yaml:P_dict.m<N>_head.h`）内的第一张进料面；更外侧的杯壁/另一堵墙不算坐面；头高区内无进料面 = 头下悬空；足印环带在坐面头侧 1e-3 mm 处全是料 = 坐面点在料里 → unknown（不报成悬空） | F-L5-2 第二半 | n_l5_fg15（C 远端台阶绿、E 料里 unknown）、n_l5_head_on_pilot_hole（悬空红） |
| **阈值 src 进判据**：criterion 写"阈值 src=measured/datasheet/assumed/缺"；无 src → unknown；assumed → 照判 + `threshold_assumed` WARN。`engagement_by_joint_type.*.range_mm`、`screw_length_rule.tip_margin_mm`、`hole_diameter_mm`（L5 只当关联容差）本轮**未**纳入 | F-L5-4 | n_l5_threshold_src |
| **结构化字段优先于自由文本，两者不一致 → unknown**：自攻盲深先读 `fasteners.yaml:<组>.pilot.pilot_depth_mm`，再退回 joins/location 正则；都有且不一致 → `screw_length_rule` unknown 并把两个数写进 detail | F-L5-5 | n_l5_pilot_depth_priority |
| **目标区间只认 frozen.yaml 声明**：碰撞在 `frozen.yaml:joint_axes[].target_range_deg` 内 → BLOCK（件的问题），全部在区间外（仍在上游扫描域内）→ WARN（工作空间问题：控制端限位，不是件的问题）；两两组合按两轴都在各自目标区间内算"区间内"。缺失 / lo≥hi / 非数 / 超出扫描域 / 人为收窄（≠上游值）却没有 `date`+`reason` → 该关节相关判据 unknown，不许退回"全部 BLOCK"或"全部放行" | F-L6-3 | n_l6_target_range_severity、n_l6_target_range_declared |
| **BAM 摩擦三处同步**（09-17）：发布 `m1.json` / 包内 `s288_m1.json` / 两个生成 MJCF 的 `chosen_actuator` 的 friction_base·friction_viscous·armature·max_torque 相对差 ≤0.2%；缺文件或缺 class → unknown。台架重测（bench BN18）改一处没改另一处 = 训练里两套摩擦 | 用户 09-17 | n_l6_bam_params_sync |
| **生成物要对着当轮实测重判，不许因"需要收窄"本身判红**：`collision_free_range` = 生成的 `sim/duck_s288/robot_walk_s288.xml` 每条 `<joint range>` ⊆ 本轮扫出的无碰撞区间（否则 BLOCK）；`gen_range_covers_target` = ⊇ 目标区间（否则 WARN，训练域被收窄）。那份 XML 是独立产物会过期，这不是同义反复 | F-L6-3 | n_l6_gen_range_vs_free |
| **网格不许比要抓的口袋粗**：两两组合统一 5° 网格（零度对齐、强制含端点），只在峰值格附近加密到 2.5°；criterion 写明步长，detail 记步长与加密姿态数。不为省时间放大网格（实测组合扫描 44 s → ≈350 s） | F-L6-1 | n_l6_combo_pocket |
| **豁免只认声明，不认"贴得近"**：最小距离判据只豁免 `relations.yaml` 里声明为 `contact` 的 `parties` 件对（`placed` 认单只实体、`part` 认该件号全部实例）；零位间隙 < 阈值但没声明的件对另发 `_zero/undeclared_zero_gap_pair` FAIL(WARN) 列出，不阻断、不豁免 | F-L6-2 | n_l6_undeclared_zero_gap |
| **算了就要判，home 不是旁注**：判据算出的每个量都得有一条 PASS/FAIL 接着；home 姿态扭矩单独一条 `static_torque_home`（同阈值），不许只进 detail | F-L7-3 | n_l7_static_torque_home_and_range |
| **评估点数 == 2 不算扫**：区间必须 lo < hi 且 `check_angles` 给出 ≥ 3 个点（2.5° 网格 + 两端），否则该关节 unknown；criterion 写明最少点数来自 check_angles 的构造 | F-L7-3 / N4 | n_l7_static_torque_home_and_range |
| **清单不全 → unknown，不给下界当绿**：整机汇总判据（static_torque / static_torque_home / com_in_support_* / head_mass_budget）在质量清单有缺口（qty>0 无质量、无 claim、认领数≠qty、定不出 body、有质量认领不到实体、qty 非整数、打印件未归属）时一律 unknown，detail 列缺口清单并只给"仅含已知质量的下界"文本 | F-L7-4 | n_l7_mass_gap_unknown |
| **阈值只有一个来源**：同一个门槛在 data 里出现两次时层只读 yaml 自述的权威键，废弃键仍在且不等 → FAIL(BLOCK, measured=差值)，相等 → INFO 提示删；不再退回 docs/ 散文 grep | F-L7-5 | n_l7_torque_source |
| **认领规则跟着元件走，不按 category 分支**：元件在 placed/ 里怎么认由 `components.yaml:components[].claim` 声明；没有 claim → `component_body` unknown（不静默漏掉）；认领到的实例数 ≠ qty → `component_qty` FAIL(BLOCK, measured=实例数) | F-L7-6 | n_l7_component_claim |
| **对数/常数/落地件/容差都从数据取**：镜像对数由 frozen.yaml 的 left_/right_ 声明推（criterion 写"== 数据声明的对数"）；home_rad 缺失 = unknown 不当 0；落地件只认 `parts.yaml:ground_contact`；筋 ±容差进 tolerances.yaml 带 src；src=assumed 的密度 / 稳定裕度 / 筋容差各发 `threshold_assumed:<键>` FAIL(WARN, measured=阈值)，src 写进 criterion | §2.6（L7） | n_l7_generalized |
| **声明式弹性接触（L4，hr41g 09-24）**：刚体扫掠超阈的**每一个**采样都落在 `fasteners.yaml` 卡扣组（`joint_type: pla_snap`）两侧特征盒之交（外扩 0.01）里、且至少一侧特征写了 `features.yaml:<特征>.elastic_contact {material: PETG（须与 parts.yaml 一致）, interference_mm: {v>0, src}}`、区内体积 ≤ 过盈 × 面积（`contact_area_mm2` 或核心盒最大面）、路径末端仍证明脱离 → `motion:*` / `elastic_contact_declared` 降为 **WARN，永不 PASS**；区外 / 超上限 / 声明缺项 / 末端未脱离 → BLOCK 照旧；拆序里靠弹性拆出的件之后每条挂 `disassembly_prereq_elastic` WARN | hr41g §2 | n_l4_elastic_declared_warn / _outside_zone / _over_cap / _missing_decl |
| **扫掠型禁入体（L3，hr41g 09-24）**：`keepouts.yaml:<KO>.bounds_world_mm` + `sweep_direction_world` / `sweep_len_mm` / `moving_components` → 包络盒沿方向平移的凸包（精确 Minkowski 和）对 placed/ **全部实体（打印件 + 元件）− 随行件** 求交；`exempt[segment=all]` 照算记数不计峰值；另判 `keepout_sweep_clear_at_end`；方向/行程/随行件任一缺 → `keepout_sweep_declared` unknown，不代跑（首例 KO22，09-25 落盘） | hr41g §3 | n_l3_ko22_sweep |
| **禁撑区按特征 id 纳入（L1，hr41g 09-24）**：`printability.yaml:no_support_zones.feature_zones.<特征 id> = {tier: forbid\|removable, face_margin_mm: {v>0, src}, why, src[, post_process]}` 把 kind 表以外的实体特征（卡扣/舌片/倒钩）纳入；区 = 每实例 `box_export_local`/`bbox_mm`/`prism` 外包盒各向外扩 margin（实体盒不外扩 = 恒 0 点假绿）；条目坏 / 特征不存在 / 与 kind 双重纳入 / 定位不到 → unknown；只有本件确用到时才进 zones_sha256（首例 B03-F03..F06 removable，09-25 落盘；登记后须重切）。反例夹具 `_harness.base_data` 只留本反例特征清单里有的条目 | hr41g §4 | n_l1_feature_zone_snap |
| **沉头锥面坐面（L4 tool_access，09-25）**：`fasteners.yaml:<组>.tool_access[].seats[].cone = {included_angle_deg: {v,src}, top_d_mm: {v,src}[, head_d_mm]}` 时，坐面点 = 孔轴上锥口顶面，足印环带（同平面坐面的 3 圈 × 24 向）落在**锥面**上、沿锥面法向 ±0.001 判"料侧有料 / 空腔侧为空"（`tool_access.cone_seat_samples`）；不写 cone = 原平面判法逐字节不变。同一实体同一孔轴上的两个孔，只有特征声明了 `depth_mm` 且轴向相距 > 孔深才算两颗（F34 两毂同轴），否则仍按"同一孔凑两颗"unknown。L5 头判据仍按平面口径，锥面坐面在 L5 `head_seat` 为 unknown（待办） | hr41 §8 / 09-25 落盘 | n_l4_tool_cone_seat |
| **六角螺母穴（L2，09-25）**：kind=cavity、shape=prism_array 且写了 `geom.hex_prism {sides: 6, across_flats_mm: {v,src}, flat_normals_export_local: [逐位置平边外法线]}` 的穴按**对边 + 对角**量：每站 12 向（6 平面法向期望 r = 对边/2、6 角向期望 r = 对边/(2cos30°)），逐向直径当量容差同圆孔（hole_diameter_mm）；通盲 / 盲深同圆孔盲穴（`step_probe` 内圈 = 内切圆 −0.3、外圈 = 外接圆 +0.3）；`across_flats_mm` ≠ `nominal_d_mm`、法向条数不符或不 ⊥ 轴 → unknown，不回退圆孔探针；没写 hex_prism 的一律走原圆孔探针（逐字节不变）（首例 J02-F04 / J03-F03） | 09-25 落盘 | n_l2_hex_nut_cavity |

---

## 4. 产出

- `scorecard.json` + `scorecard.md`：17 件 × 8 层矩阵，每格 {状态, 数值, 证据数, 输入 hash, 过期?, 豁免?}。只有**全量跑**写它和 `scorecard.prev.json`；`--layers/--parts` 子集跑写 `scorecard.partial.{json,md}`（`partial: true`，不是放行依据）
- `negatives.cache.json`：反例包结果缓存（key 见元规则 8）；`gate.py --no-neg-cache` 强制重跑
- `gate.py --verify [scorecard.json]`：核对记分卡绑定输入是否还原样（元规则 6）
- `impact.md`：**这次改动让哪些格子变了**（换件后只读这个，不读全表）
- `fastener_bom.md`：从 features + fasteners 自动生成的螺丝采购单
- `mass_budget.md`：每 body 质量重心 vs MJCF、各关节静扭矩占额定比、头部质量上限（由颈部扭矩倒推）

## 5. 换件的完成定义（DoD）

改 `components.yaml`（和必要的 features/harness/keepouts）→ 跑 Gate → 读 `impact.md` → 清 BLOCK → 质量漂移超阈值就更新 MJCF `<inertial>` 并标注是否重训 → 同步 `06_CAD源码/` → 记分卡与 STL 同一 commit。

## 6. 改 Gate 代码的硬规矩（hr42 / L1 事故后，2026-09-25）

- **`layers/l1_printable.py` 任何改动（包括只为提速的改动）都必须连带重跑 `./.venv/bin/python -B tools/gate/calibrate_l1.py`**：标定记录 `l1_calibration.yaml` 的指纹包含该文件源码，不重跑则 `L1/_calibration` 判 BLOCK。约 2 min / 700 MB。
- 打印 / 交付 / 复审前的全链必须无缓存实跑：`DUCK_BUILD_CACHE=0 DUCK_CHECK_CACHE=0`（或各脚本的 `--no-build-cache` / `--no-check-cache`），并带 `PYTHONFAULTHANDLER=1`；日常改件用默认增量（命中格 evidence 标 `cached_from`），增量结果不是放行依据。
- 跑重活一律挂进程树 RSS 看门狗（机器 18 GB，超 10 GB 直接杀）；2026-09-25 L1 层曾因 H01 新朝向的支撑模型顶点爆涨吃到 63 GB + swap，根因与修法见 `docs/design_2026-09-17_bearing_rebuild/hr42_work/l1_incident/报告.md`。
- 检查原语缓存目录 `tools/gate/out/check_cache/` 会长到几百 MB，隔段时间清；并发跑多个 gate 子集时它是共用的，结果可疑先 `DUCK_CHECK_CACHE=0` 重跑再判断。

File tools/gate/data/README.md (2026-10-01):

# `tools/gate/data/` —— Gate 读的 12 个数据文件

规则只写不变量，一切"应该是什么"都在这里。**换件只改这里，不改检查器。**
全部由 `docs/gate/inventory_v2.json` + `inventory_original.json` + `comparison_original_vs_v2.md` 转换而来，不是重新盘点。

| 文件 | 一句话 |
|---|---|
| `components.yaml` | 19 个外购/占位元件：外形·质量·安装·接口·线缆·禁入·装入方向。换件的**入口**。 |
| `parts.yaml` | 17 个打印件（件号 L01…H03 为 key）：build 函数名·材料·打印朝向·镜像·装了哪些元件。 |
| `features.yaml` | 151 条特征：孔/沉头/槽/凸台/夹持面/让位/扫掠刀。只定位与追溯，判据去 `tolerances.yaml` 取。 |
| `fasteners.yaml` | 30 组 157 颗螺丝（+2 扎带 +2 卡珠）：规格·叠厚·咬入·**每颗自己的 `tool_envelope`**·驱动方向·状态。 |
| `assembly.yaml` | 19 步装配序（含 `already_installed` 累加）+ 8 条拆卸序。第 4 层照它逐步扫掠。 |
| `relations.yaml` | 22 条功能关系 + comparison C1/C2/C3 三条 Gate 条目（IMU 外参 / 少掉的轴承 / L03 刚度）。 |
| `keepouts.yaml` | 21 个禁入体：视锥·声孔·摆动扇区·电池抽出·接口·刀路·线束空间。 |
| `harness.yaml` | 9 束线：折线·径·最小弯折半径·两端插头·长度预算·跨哪个关节。现状 5 束完全没模型。 |
| `frozen.yaml` | 不许动的：15 条关节轴线·电池仓 26 项·SHELL_BOSS·H01 立柱·6 个原版 STL 的 sha256·躯干 IMU 位姿·C5 只对照不打印名单·C6 接口预算。**唯一允许硬编码世界坐标的文件。** |
| `tolerances.yaml` | 公差表：咬入按连接类型分，配合按 **材料 × 打印方向 × 特征类型** 分桶；顶部 `placeholder_summary` 报"还有几个配合靠占位值"。 |
| `waivers.yaml` | 豁免。**现在是空的。** 只有 WARN 可豁免，绑定输入 hash，输入一变自动失效。 |
| `bench.yaml` | 14 项实机验证：只放离线算不出来的，判据数字现在就写死（`value_status: proposed`），到货逐项打勾。 |

## 换件时改哪几个文件（对应 `tools/gate/README.md` 第 5 节 DoD）

1. **必改** `components.yaml`：那条元件记录（外形/质量/孔阵/接口/线缆/装入方向）。
2. **跟着改**（按新件是否动到）：
   - 动到孔位或让位 → `features.yaml`（该件的特征）+ `parts.yaml`（`houses`）
   - 动到螺丝 → `fasteners.yaml`（长度、叠厚、`tool_envelope`）
   - 动到接口/视锥/声孔/抽出路径 → `keepouts.yaml`
   - 动到线 → `harness.yaml`
   - 动到装/拆顺序或方向 → `assembly.yaml`
   - 动到配合（新的间隙/过盈/滑配）→ `tolerances.yaml` 的对应桶 + `relations.yaml` 的那条关系
3. **一般不改**：`frozen.yaml`（改它 = 解冻流程，要人签字并说明是否重训）、`bench.yaml`（除非新件带来新的实机风险）、`waivers.yaml`（只增不改）。
4. 然后：跑 Gate → 读 `impact.md` → 清 BLOCK → 质量漂移超阈值就更新 MJCF `<inertial>` → 同步 `06_CAD源码/` → 记分卡与 STL 同一 commit。

## 字段约定

2026-09-12 清红补充（只声明事实与检查义务，不是放行标签）：
- `parts[].placed_instances`：按 BOM `qty` 列出全部导出实例，首项为左件；缺失、重复、跨件复用均失败。`motion_instances` 给每个 placed STL 唯一的 MJCF body 归属；目前 52 个。
- `features[].geom.instances` 必须有 `count_kind: instances|cylinders`，分别表示组数或展开后的总柱数；组内阵列的 `count`/`holes` 是孔数，必须等于坐标数。重复整组不能补齐漏孔。同心异径或分段柱仍是不同几何。
- `assembly_order[].required_motion_groups` 独立声明动作 ID、工位、移动组及在场全集；`motions` 必须逐一覆盖。`sense: withdrawal_from_assembled` 表示从最终配合位抽出，反演为装入；全体刚性组沿同一向量移动，终点须完全脱离。
- `fasteners[].head_locator_map_indices` 先声明头侧孔全集，`tool_access` 必须覆盖它。每个 `state_ref` 指向 `motion:<step>:<id>` 的工位或 `tool:<id>` 的显式拧紧工位；坐面通过 `map_index/hole_index` 绑定已有 `feature_hole_map`，声明 `point_export_local/outward_export_local/instance`，不能拿孔中点代替。同一实体同一孔轴不能跨映射重复凑数。
- `features[].geom.hole_positions_mm` / `geom.instances[].hole_positions_mm`（= `fasteners[].feature_hole_map[].holes`）是**刀心**（切刀中点），不是坐面、也不一定在件上（40 mm 的刀切 3.6 mm 的板，刀心离件 15–19 mm 甚至在件外）。L2 用 `axial_span_mm` 兜住孔身范围；其它层不许拿它当坐面或射线起点，只能当轴线锚（校验点在孔轴上）；头/坐面一律用 `fasteners.yaml:tool_access[].seats[]`（`point_export_local` / `outward_export_local`，键带 `instance`）。（2026-09-13，F-L5-2 第二半）
- `tool_envelope.bit_d_mm` 是本组批杆包络；`available_shaft_len_mm` 是可用杆长。旧 `shaft_len_mm` 多数是反算需求下界，`channel_*` 是内腔，两者都不能当可用工具规格。缺实际数据继续失败。
- H03-F02 是孔身，H03-F04 是四段扩口。F22 的径向自攻必要条件为 −0.1 mm，属于配合不兼容；不能归为“补字段即可放行”。（2026-09-13 起已过时：09-12 I4 在 H03 先填 Ø3.6 后自钻 Ø1.7×7.0，H03-F02 重写为自攻底孔、H03-F04 删除、新增 H03-F05 填柱，径向重叠 +0.15；见 CHANGELOG 2026-09-13『Gate 数据对表 build #7』。）

- **`provenance`**：每条记录必须有，值是列表。格式：`duck.py:行` / `s288.py:行` / `ankle_split.py:行` / `asmcheck.py:行` /
  `mechanical_audit.json:键` / `inventory_v2.json:路径` / `inventory_original.json:路径` / `MJCF:行` / `comparison_original_vs_v2.md:编号`。
  **没有出处的条目不许写进来。**
- **数值字段**：统一 `{v: <值>, src: measured|datasheet|assumed}`，可选 `src_note` 记原始表述。
  - `measured` = 实测（`s288.py` 里标 `[量]` 的、射线量出来的、从原版网格量出来的、audit/report 里的数）
  - `datasheet` = 手册 / 商品页 / 标准件规格
  - `assumed` = 采用值（`inventory_v2.json:assumed_values` 那 20 条全部在 `tolerances.yaml:assumed_values` 里，全是 `assumed`）
  - **混合表述按最弱一环取 `assumed`**（元规则 4：未知=失败，保守优先）
- **搬不过来的值**：`v: null` + `unknown_class` + `unknown_reason`。`unknown_class` 只用这 6 个：
  `not_measured`（没量）/ `not_audited`（几何在但没跑检查）/ `not_modeled`（CAD 里就没有）/
  `not_selected`（选型未定）/ `not_applicable`（本来就没有这个概念）/ `no_source_given`（清单没给来源）。
- **`deliberately_absent` / `deliberately_added`**：comparison 文档 A 段 16 条 / B 段 11 条的落地记录，带 `comparison` 编号和理由。
  **看到"原版有我们没有"就想补回来之前，先读这两段。**
- **`discrepancies` / `conflicts`**：两份 inventory 互相对不上的地方（D-COMP-01…03 / D-PART-01…02 / D-FAST-01…03 / D-FROZEN-01…03 / seat_d / pilot_hole_d）。别当噪声删掉。
- 不许在规则数据里硬编码"这个件在世界坐标哪里"，除非它本身是冻结项。特征用相对本件基准的描述；判据用范围不用单值。

## 2026-09-13 审计第二批新增字段（换件只改这些，层不再写死）
- `components.yaml:components[].claim`：元件在 placed/ 里怎么认领（`by: mjcf_servo_geom | envelope_ring | envelope_box | placed_prefix`，见文件头注释；L3/L7 同一份）。`envelope_solid`：第 3 层独立建实体的声明（`shape: ring{bore_mm, od_mm, t_mm} | box{size_mm, overall_mm, exact} | none{why}`（box 的三边按 overall_mm 与 placed OBB 三轴长度配对；两个 overall 值差 <0.5 且对应 size 不同 → unknown）），落位只借 placed 的 OBB，尺寸不许抄 CAD；没声明 → `envelope_solid_declared` unknown。
- `keepouts.yaml`：`checked_in_layer`（4/6）+ `covered_by_subjects`（该层格子名）—— 扫掠/运动类禁入体的义务派给真查它的层；KO01 `dims`（plug_top_x/wire_out/conn_z/plug_clr/plug_y_in/side_exit_y/window_x/hub_keep_d）+ `availability_table.rows[].mode_pos_y|mode_neg_y`（独立实体，不借 CAD 切刀；09-20 背插模型）；KO06 `servo_frame_of_joint`、KO07 `axis_joint`、KO11 `probe_zone_z_mm`、KO12 `exempt[]{part, segment, why}`、KO15 `fov_deg / apex_world_mm / optical_axis_world`。缺任一 → 对应判据 unknown。
- `frozen.yaml`：`joint_axes[].target_range_deg{v, src[, date, reason]}`（第 6 层目标区间：缺省 = 上游 MJCF；人为收窄必须带 date+reason）；`battery_bay_26.measured_on{bay, door}`、`h01_sbc_posts.measured_on / post_axis_world`、`imu_pose.measured_on / mount_hole_d_mm`（第 3 层冻结项实测的落点）。
- `printability.yaml:parts.<件>`：`down_world / fill_density_percent / perimeter_generator / slicer_args`（切片脚本逐件配置，缺 → 退出）；`no_support_zones.tiers / per_feature_overrides`（两级禁撑区）。
- `tolerances.yaml`：阈值节点必须带 `src`（`assumed` 照判 + `threshold_assumed` WARN，缺 → unknown）；新增 `feature_check_tolerances.frozen_dimension_mm / envelope_vs_placed_mm`、`load.min_section_and_rib.rib_declared_vs_measured_tol_mm`。
- `parts.yaml:parts[].ground_contact: true`：第 7 层落地件（不再按材料文本猜）。

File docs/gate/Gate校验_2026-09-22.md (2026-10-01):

# Gate 与验证方式校验（2026-09-22，依据 hr29 记分卡 + hr30 真实姿态采样）

口径：只盯三个目的 —— **装得成、关节转得到、动起来不撞**。只列影响这三条的纰漏；**不新增判据**，修法一律是"让已有判据真正咬到数据"或改件。
依据文件：`docs/gate/scorecard_2026-09-21_hr29.json`、`tools/gate/out/policy_steps_2026-09-22_hr30/{compare.json,poses.jsonl}`、`tools/gate/layers/l4_assembly.py / l6_motion.py`、`tools/gate/tool_access.py`、`tools/gate/probe_seats.py`。

## 一、动起来不撞

**1. 真缺陷：H03 下头壳 × N02 颈俯仰件（`head_bottom_shell×neck_pitch`）。**
真实姿态 5601 个里 **1502 个碰**（走路 1293 / 站立 146 / 坐站 63），峰值 55.6 mm³。走路最坏姿态（颈俯仰 −22.8°、头俯仰 −23.8°、头偏航 −53.6°、头横滚 −22.9°）交集 31.5 mm³，位置 x 36–54、y −17.5..13、z 209–214.5 = **H03 下沿前部 vs N02 顶前缘**；头全朝上（颈 +25.6 / 头俯仰 +58）也擦 3.7 mm³（x 16.6–20.4、y 12.5–16.9、z 204–207 = 脸颊侧）。
- hr10 起每一轮都是 1502–1507 姿态 / 55–60 mm³，从未变过；hr23 脸颊外移曾涨到 1628 / 121，hr24 撤回后回到 1502。
- 原版同一对也碰（59.6 mm³）—— 原版这块是 TPU 软嘴（jaw_soft），我们的 H03 是 PETG。compare 的 acceptance 明写 `upstream_shared_is_not_exempt`，这一对**不豁免**。
- 记录.md 第 208 行只写了 hr23 的**增量**（122 姿态 / 6.1 mm³），基数 1502 从没进过待修清单。这是碰撞目标上最大的一条漏项。
- 处置（要用户拍板）：改件 —— H03 下沿按真实姿态里 N02 的扫掠体减让位（同 N02-F14 的做法：真实姿态并集 + 公差），或 N02 顶前缘削。改完是几何轮（新采样目录 + 全量）。

**2. 验证方式：L6 `_capability/real_pose_collisions` 连续多轮没采信。**
hr28b / hr29 都是 "采样生成指纹不完整/过期"。原因核实：采样指纹含 `tools/gate/data/*.yaml`、`duckstructure/*.py`、`l6_motion.py`，hr29 采样后又改了 features/components/fasteners/assembly/printability/harness 六个 yaml 和 l6_motion.py → Gate 拒认。**5601 姿态的证据一直只在 compare.log 里被人读，从没进过分数。**
hr30 已核：`policy_steps_2026-09-22_hr30/summary.json` 指纹与当前计算**完全一致**，本轮是第一次按实绩打分，预期 BLOCK（有命中即红）。
规矩（不是新判据）：采样必须是 Gate 前最后一步；采样到 Gate 出分之间不碰 yaml / duckstructure / l6_motion.py。`hr30_go.sh` 已按此顺序。

**3. 元件从未进过碰撞检查。** 18 个元件无世界坐标（L3 `world_placement` 红），其中影响碰撞的：Radxa（头内 H01 立柱）、摄像头（脸板，镜座凸 14）、IMU（T01 前壁）、UBEC（T01 −y 侧腔）、开关（T02 壳顶）、一分二 ×5、麦克风。现在只有 zz_battery / zz_adapter 两个占位块进了 placed/（电池占位 18×25×72 与已确认实物一致）。IMU 的 9.9 / 6.7 mm 净空只来自 scratch 扫掠脚本，不在 Gate 里。
最小修法：`build.py` 照 zz_battery 的做法加 zz_sbc / zz_camera / zz_imu / zz_switch 占位块（尺寸 datasheet 都有：65×30 / 32×32×16 / 25.4×17.8×4.6 / 21×15×20），UBEC 到货卡尺后再加。L3 静态交集与 L6 运动扫掠会自动把它们带上，不加判据。几何改动 → 新采样目录 + 全量。

## 二、关节转得到

**4. 已验证、口径合理。** 单轴 14 条：目标区间内 0 碰（5 条 WARN 全在目标区间外）。真实姿态 7 个"我们独有"缺陷对全部 < 1 mm³ 且都在 alpha_stand。两两组合目标区间内 2345 条全是包络盒**角点**（膝 +90 / 踝 −75 脚×大腿舵机 5469 mm³；颈 +60 / 头俯仰 −55 嘴×电池 8271 mm³），真实策略没走到 —— 盒角 WARN、真实姿态 BLOCK 的分档是对的，不要把盒角升 BLOCK 去逼改件。

**5. 重训前置（已有红项，不是新判据）。** 我们生成的 MJCF 只有脚有碰撞几何（`_simmodel/collision_geom_coverage` 红，mjlab 还会把 col_* 关掉）。重训后的策略**可以**走到第 4 条那些盒角组合而仿真毫无感觉。重训前必须：生成的 MJCF 全 body 碰撞几何 + mjlab 不关；重训后用**新策略**重新 dump policy_steps、重推 target_range、重采真实姿态 —— 现在的目标区间和 5601 姿态都来自原版策略。

## 三、装得成

**6. 起子可达 30 组 0 通过 —— 157 颗螺丝的可达性实际处于未验证。** 18 组 `tool_reference`（坐面不在孔轴上，判据 1e-6）+ 9 组 `tool_origin_on_seat` = 27 组（hr29 是 19+9=28，hr30 修了 F26）。坐面数据是 09-12 probe_seats 量的，09-13 FG12 收紧后整体变红，此后一直没重生成；hr30 手写在孔轴上的 F26 坐面能过，说明是数据不是判据。
修法：对当前 placed/ 重跑 `tools/gate/probe_seats.py`，把 tool_access 坐面全部重生成并落在孔轴上（脚本本身沿声明轴取样，输出应在轴上；若不在，是脚本与判据的 1e-6 口径不一致，改脚本不改判据），逐组人看候选面。数据轮。

**7. 装配步的“已装件”清单漏写了已装好的轴承 → 扫掠少了障碍，可能假绿。**（不是采购缺件：轴承已定、已在购物车；这里说的是 assembly.yaml 每一步 / 每个工位的 present 列表没把 seq 11 装进去的两个头部轴承写上，Gate 扫掠时当它们不存在。） hr30 记分卡 `present_covers_derived` 红 11 格：step15（neck_servo_into_N01）、step18（H03_bottom_shell / top_head_shell）、tool 工位 H02_on / N02_on_headyaw / head_on_headpitch / head_shells_on / headyaw_servo_in_N03 / neck_servo_in_N01 都缺 `bearing_head_roll_A`、`bearing_head_yaw`；tool 工位 hiproll_flange_L / _R 各缺 `hip_pitch_sleeve` / `hip_pitch_sleeve_R`。只改 assembly.yaml 的 present 列表，数据轮；**建议并进 hr31**（hr31 已要重采 + 全量，省一轮 45 分钟）。

**8. 电子件装入这一步没有路径模型。** step19（Radxa 上立柱 / UBEC / 分线 / 开关 / IMU）`path.kind=null`，从未扫掠；IMU 已有 `tool:imu_install` 工位但没有装入 motion。与第 3 条一起做：占位块进 placed/ 后，step19 拆成逐件 motion（IMU 沿 +x 贴前壁、Radxa 沿 −z 落立柱、开关沿壳顶法线、UBEC 进侧腔）。

**9. 不动的。** 线束 9 束 route 未建模（用户定：待实物）；disasm06/07 拆序数据缺 reverse_of_step（数据，顺手补）；L7 扭矩表已含 datasheet 0.6 + 09-16 实测 0.66（连续扭矩仍 null，靠 BN03）。

## 四、明确不加的

- 不加"盒角组合 BLOCK"、不加线束新判据、不加元件级新判据、不给 L1 支撑加阈值。
- 不改 acceptance（`upstream_shared_is_not_exempt` 保留 —— 第 1 条正是靠它才不被原版掩盖）。

## 五、建议顺序（hr30 ✅122 ❌392 已出）

| 轮 | 内容 | 性质 | 验证 |
|---|---|---|---|
| hr31（另一 agent 已备好：T01-F20 → pilot_hole、F26 杆长、tolerances 文案） | **建议并入第 7（present 补件）**；第 6（probe_seats 重生成坐面，要人看候选面）和第 9 拆序数据可留 hr32 | 只改 yaml | 新采样目录 + 全量（yaml 进指纹） |
| hr32 | 第 1（H03/N02 让位，**需用户定改法**）+ 第 3/8（元件占位块 + step19 motion） | 改件 | 全链 + 独立复审 |
| 重训前 | 第 5 | MJCF/mjlab | col_check + 新策略重采 |

---

# 六、决定（2026-09-22 02:xx，给执行 agent；用户授权由本 agent 定）

## hr31 = 数据轮（现在做；下面 A/B/C 并成同一轮采样 + Gate，不分开跑）

**A. 已备好的 hr31 改动照旧**：`hr31_sync_data.py`（T01-F20 → pilot_hole、F26 杆长 58.4、tolerances 文案）。`l6_motion.py:79` 已指向 `policy_steps_2026-09-22_hr31`，`hr31_go.sh` 会 rm 重采，不用改。

**B. assembly.yaml present 补件（只加名字，不动别的）。** 记分卡的 stepNN 是文件顺序不是 seq，下面按 motion id 说：
- motion `neck_servo_into_N01`（seq 16）、motion `H03_bottom_shell` 与 `top_head_shell`（seq 14）的 `present`：各加 `bearing_head_yaw`、`bearing_head_roll_A`（两者在 seq 11 装入，早于这些位置；名字与 placed/ 一致）。
- `tool_states` 的 `H02_on` / `N02_on_headyaw` / `head_on_headpitch` / `head_shells_on` / `headyaw_servo_in_N03` / `neck_servo_in_N01`：present 各加同样两项。
- `tool_states.hiproll_flange_L` 加 `hip_pitch_sleeve`；`hiproll_flange_R` 加 `hip_pitch_sleeve_R`。
- 预期：11 格 `present_covers_derived` 转绿；对应 `step_sweep` / `tool_path_to_outside` 因为障碍多了两件**可能新红**——那是真结果，照实记，不在 hr31 里修件。

**C. 起子坐面全部重生成（fasteners.yaml tool_access）。** 根因已查明：S288 分度圆定案 Ø10.5 后法兰孔从半径 4.75 重算到 5.25（F02 hole_map 已是 5.25），tool_access 的坐面点还停在 4.75 → 判据 1e-6“坐面不在孔轴上”整体红；背孔组（F01 等 9 组）同理起点不在坐面。修法：
1. `./.venv/bin/python tools/gate/probe_seats.py --groups <27 组> --out <片段.yaml>`（27 组 = hr30 记分卡里 tool_reference / tool_origin_on_seat 红的 L4/F* 格，见 §三 6）。本 agent 试跑 F02：12/12 坐面过探针、每孔候选面唯一、点落在 (5.25, 0, 0.5) 孔轴上；全 28 组试跑结果见下 **C-结果**。
2. 只接受日志里 `OK` 且 `cands` 恰好 1 个的孔；候选 ≥2 或失败的组**列出来停下**，不猜。
3. 把片段里每组的 `head_locator_map_indices` + `tool_access` 整体替换进 fasteners.yaml 对应组（`state_ref` 用脚本给的，先 grep 确认 `assembly.yaml:tool_states` 里有同名工位）；加一句 `seats_regenerated_2026-09-22: probe_seats 对 hr29 件重生成（Ø10.5 分度圆后旧坐面停在 r 4.75）`。
4. 风险有界：坐面写错只会红（探针 / 足印 / 孔轴三道校验），不会假绿。
- 预期：27 组 `tool_reference` / `tool_origin_on_seat` 绿，之后 `tool_path_to_outside` / `screw_head_visible` **第一次真跑**，会出一批真红（批杆被邻件挡）；逐组记进记录，不在 hr31 修件。`tool_reach_declared` 保持红（available_shaft_len_mm 实物未知，不编）。

**C-结果（本 agent 02:xx 对 28 组试跑）**：27 组分批跑（首轮一次性跑 27 组在第 11 组 F11 颈俯仰背孔上卡 8 分钟、内存 1.2 GB，杀掉改分批）。**替换 9 组**（全部坐面过探针、每孔候选面唯一、坐面数 = qty、坐面在孔轴上 1e-6、工位/动作存在）：F02 / F04 / F08 / F10 / F12 / F12b / F16 / F17 / F20。**不动 18 组**：F06 髋俯仰法兰 2 孔找不到料→空面（10/12）；F14 / F14b 头俯仰法兰/惰轮 6 孔每孔 2 个候选面（N02 脸颊有 hr26 挖穿槽）；背孔 11 组（F01 / F24 探针脚本 SPEC 无此组；F03 0/4、F05 4/8、F07 4/8、F09 4/8 找不到面或 2 候选；F11 / F11b / F13 / F15 / F18 首轮卡死未跑）；F23 / F25 / F29 / F30 探针脚本 SPEC 无此组。这 18 组保留原数据、继续红，留 hr32（要么给 probe_seats 补 SPEC，要么人对着候选面挑）。证据：`docs/design_2026-09-17_bearing_rebuild/hr31_probe_seats.log` + `hr31_probe_seats_fragment.yaml`；写入脚本 `hr31_sync_data_part3.py`（dry-run 核对后 --apply）。旧坐面 vs 新坐面例：F02 (4.75, 0, 1.7) → (5.25, 0, 0.5)（孔 (5.25, 0, 15.35)），F17 (−14.8, 0, 9.75) → (−12.45, 0, 9.25)。

**D. 跑法**：A+B+C 全部落盘 → 确认 `tools/gate/data/*.yaml` 都能 parse → `zsh docs/design_2026-09-17_bearing_rebuild/hr31_go.sh`（约 45 分钟）。跑起来之后不碰 yaml / duckstructure / l6_motion.py。出分后 score_diff 对 hr30，填 README / CHANGELOG / 记录 38 的三处 hr31 占位，复审用 `hr31_review_brief.md`。

**hr31 已跑（02:35–02:55，本 agent）**：✅130 ❌384（hr30 ✅122 ❌392）。B 的 11 格全绿；C 的 9 组坐面/起子路径/头可见 8 组全绿、F20 出真红（下）；真实姿态 17/7/7 不变。hr31 冒出的两项加进 hr32（**复审 `hr31_review.md` M-01/M-02 已纠正本段初稿的两处错判**）：**4** `stack_from_seat_crosscheck` 4 组红的定性 —— F04 / F16 / F17 的登记值 7.5 / 5.25 / 5.25 **是对的**（多件叠层：宿主件 + 0.3 隙 + 轴套/转接盘，复审用射线逐件核过），红是 L5 `_seat_end` 只量宿主件第一段连续实体（2.7 / 2.5 / 3.15）；**不改这三组的 stack_mm**（改了会连累 engagement_derived / screw_length_rule）。处置二选一：(a) 让 `stack_from_seat_crosscheck` 沿孔轴把工位 present 里的实体串起来量到接收件（让已有判据咬到真数据，不是新判据）；(b) 不动层代码，加归因注释。只有 **F12b 是真旧值：stack 5.55 → 5.40、engagement 2.45 → 2.60**（09-14 CHANGELOG 写了没落到 fasteners，同 hr27 改 F14b 那类漏改；本文初稿写的“记 5.25”是错的）；**5** F20 壳螺丝顺序（起子 +z 118 mm 被头壳挡：颈子总成先不带头上躯干、壳拧完再装头，或壳螺丝换方向）；F26 的 head_seat / engagement_per_hole：复审指出这两条**就是 part1 预期的 unknown**（core.unknown() 记成 FAIL/BLOCK/measured=None），hr30 的两条假红、五条假绿都没了，part1 目的达到；而且照 zz_battery 写法加 zz_imu **解决不了**这两条（L5 要导出件 STL + frame + 特征 + hole_map 改指 + 坐面 instance，zz_* 只进 placed/）。hr32 要先定：(a) 把 IMU PCB 按“非打印占位件”完整登记（parts.yaml 现在没有这个字段，L0/L1 会把它当打印件跑）；或 (b) 走 waivers，明确“非打印件 Gate 不量”，从待清单拿掉。**本 agent 建议 (b)**：IMU 只有 2 颗 M2×4，咬入 2.4 已由 hr30 手算核过，不值得为它给 Gate 加一类件。
**5-补（复审 D）** F20 顺序改法不等几何轮：拆 seq 16（颈子总成不带头上躯干 → 壳 → 头上颈），改序后 `tool:shells_on` / `tool:head_shells_on` 的 present 与 `subassemblies.robot.note` 同步；只改 assembly.yaml，可并进 hr32 前的数据小轮。
**复审补充采纳**：几何轮拆两步 —— 先做 H03 让位单独出一版真实姿态（只盯 `head_bottom_shell×neck_pitch` 1502 → 0），再叠占位块，否则 L6 新增对无法归因。F14 / F14b 每孔两候选面（−44.85/−15.45、−25.85/3.55）是 hr26 脸颊挖穿槽造成的第二张面，“取离孔最近”选的 −15.45 / 3.55 应当就是真坐面，人对着看一眼即可接受，不必等改脚本。顺手项：8 组 `stale_since` / 旧探针键退役、probe_seats.py provenance 写死的 2026-09-12、T01-F20 geom 重复键去重、`seat_table` 双件组（F20 永远判不了头坐面）。

**hr32 已启动（09-22 09:00，本 agent，`hr32_go.sh`）**：只做第 1 项（H03 让位，试 build 削 349.8 mm³ / 6 块、16 试验姿态归零、口袋与 N07 通道 0 交集）+ 复审要的数据小修（F12b 5.40/2.60、旧探针注释退役、T01-F20 去重）；占位块 / F20 顺序 / 18 组坐面 → hr33。F26：waivers 只收 WARN、这两条是 BLOCK，“走 waivers”不成立，只剩“非打印件完整登记”或接受红。

**hr32 出分（10:10）✅130 ❌384（= hr31）**：让位达成 —— L6 `head_yaw+head_roll` 目标区间内 0，真实姿态 head_bottom_shell×neck_pitch 1502 → 5（峰 3.14 mm³；5 个都是 alpha_stand 里 head_roll −26.8..−28.2°，超出 frozen 目标 ±25°；策略实际包络 roll −28.15..24.04）→ hr33 扫掠改按策略包络。新红：L0 `_release` ×2（未同步）、L2 `H03-F11:occupancy`（薄片实例外包盒中心在料里，数据修）。
**第 10 项（本轮新抓）：全链里真实姿态采样被 slice 合并作废。** `hrNN_go.sh`（hr29 模板）把采样和 A 组审计并行，之后才 `slice_l1 + merge_slice_run` 写 `printability.yaml`；采样指纹绑 `tools/gate/data/*.yaml`，于是 Gate 的 `real_pose_collisions` 在 hr29、hr32 都是 unknown（"采样生成指纹不完整/过期"），只有不 slice 的 hr30/hr31 有数。这条判据恰是关键指标（真实姿态碰撞），空了两轮没人看见。规矩：采样是 Gate 前最后一步，slice/merge 在它之前；hr32b 起照此，hr33 链模板改序。
**hr32b（10:20–11:0x）✅131 ❌383**：H03-F11 实例 4/5 bbox→extent、发布目录同步、重采到 `policy_steps_2026-09-22_hr32b` → Gate。L0 两条 + L2 H03-F11 转绿、0 倒退；`real_pose_collisions` 第一次在"改件轮"里有数：88/5601 姿态（hr31 1512），剩 15 对全与 H03 无关（脚踢头/嘴、髋-踝后臂等站立/翻滚模式的原版同类对）。第 1 项（§一 1）到此算关（残余 5 姿态 = 目标区间外，hr33 扫掠按策略包络收尾）。 复审 `hr32_review.md` BLOCKER 0 / MAJOR 2 / MINOR 6：M-01 head_specs 指纹、M-02 H03 贴床 79.2 → 17.3 mm²（切片开 brim）、m-01 夹点顶点（L0 盲区 → 加 `nonmanifold_vertices`）、m-03 链模板；复审对扫掠范围倾向 (a) 让位刀按策略包络（roll −30..25 或 ±30）、frozen 目标区间不改。
**效率决定（用户 10:1x 提出"一次只改一处太慢"）**：hr32 全链 70 min（重切 19 / 扫掠 10 / 采样 14 / Gate 30+，其中 L1 27 min），跟改动相关的计算不到 5 min。① hr33 起多处改动合一轮，"一次一处"降级为"一个件一轮只改一次"，新冒出的碰撞对靠件名归因；② 加快车道：build 单件参数、audit_motion / 采样按件过滤并复用上一轮其它件对（复用前逐件核 sha）、Gate `--parts`，单件小改 5–10 min 出局部结论；交付/复审前、改 assembly 结构或 Gate 层代码时仍全链。
**快车道已落地（12:xx）**：`fast_lane.sh` = `build_fast.py --only`（缓存 `cad/duck_s288/cache/*.npz`，build.py 末尾 `write_cache`）→ `audit_motion.py --parts` → `policy_pose_delta.py --parts --reuse --snapshot`（其它件对复用、逐件核 sha）→ `gate.py --parts`。自检见记录 40（快建产物与全量逐字节相同；增量采样与 hr32b 逐对逐值相同）。**边界**：快车道结论只用于迭代；`_capability real_pose_collisions` 认的是 `l6_motion._REAL_POSES` 指向的全量目录，快车道不改它；交付/复审前跑全链。
**hr33（12:07–12:50）✅129 ❌385 / hr34（12:57–13:18）✅133 ❌382**：第 1 项闭环 —— 让位刀横滚 ±30（策略包络 −28.15..24.04 外扩，frozen ±25 不改）+ grow 0.45：真实姿态 H03×N02 **0**（84/39/16），H03 夹点 0；第 5 项（F20 顺序）闭环 —— 头子总成改在壳后挂（新步 20），F20 起子 reach 51.2 / 4 颗头可见，顺带消掉 step17/shells_on 三条"头件未装却在场"旧红。新判据 `nonmanifold_vertices` 全量首跑揭出 H01 ×1 / L05 ×3 旧夹点（WARN）。剩余：占位块（第 3/8）、18 组坐面（第 6）、F26（第 9）、H01/L05 夹点、L1 H03 贴床 8.9 mm²（brim）。
**hr35（14:50–15:20）✅133 ❌383 / hr36（15:21–15:50）✅134 ❌382**：hr33 复审 M-02 闭环 —— F14/F14b 坐面重生成后壳后拧的三条路径判据全绿（reach 55.6，峰 0，6/6 可见），拆序新增 seq 0 头子总成整体提起（0.0），L5 F14/F14b 坐面四项有物可量；M-01 梳齿四种修法（并集平滑/grow 0.75/闭运算/开运算）均无效或更差，判为壳皮薄鳍而非刀参数，切片会丢 → 有据接受。hr35 揭出的两条（发布包 build_fast.py 未同步、F14 叠厚旧值 3.55）hr36 修回，恰好两条转绿 0 新红。18 组坐面 → 16 组；起子杆长未知 13 → 15 组。复审 § hr35 复核 BLOCKER 0。

## hr32 = 几何轮（hr31 出分后；改件 → 全链 + 独立复审）

**1. H03 下头壳给 N02 让位（§一 1）。** 事实：H03 在 body `jaw_soft`，N02（placed 名 `neck_pitch`）在 body `neck_pitch`，MJCF 链 neck_pitch →(head_yaw) yaw_roll_motion →(head_roll) jaw_soft，所以两件的相对运动**只有 head_yaw × head_roll 两条轴**（颈俯仰、头俯仰两件一起动）。L6 两两组合也正是 head_yaw+head_roll 这格：目标区间内 233 条、峰 52.4 mm³ @ yaw +85 / roll +25。
- 做法：`head.py:build_head_bottom_shell` 末尾加一把让位刀 = 把 placed N02 实体按 head_yaw ∈ [−116.4, 95.4] × head_roll ∈ [−25, 25]（frozen.yaml target_range_deg，含端点）5° 网格（44×11 = 484 姿态；本文初稿写 473 是错的，复审 m-02）变换到 jaw_soft 坐标系求并集，膨胀 0.4（tolerances min_gap 0.3 + 0.1），从 H03 减掉。变换用 duckstructure.lib 的 FK（imu2/sweep 脚本同一套），不手写旋转。
- 约束：不碰 H03-F08 转接板口袋（z 226–240）与 N07 起子通道；刀削掉的体积 > 2 cm³ 或把外皮打穿 → 停下报用户（那就要改用真实姿态集或削 N02 顶前缘，用户定）。零位 H03 贴脸颊那条接触带会被切掉 0.4，先查 relations.yaml 有没有把这对声明成 contact，有就同步改。
- 登记：features.yaml 新 `H03-F11`（kind sweep_cut，spec 写清两轴区间与膨胀）、parts.yaml feature_count、CHANGELOG、记录。
- 验收：真实姿态 `jaw_soft×neck_pitch` 0 姿态；L6 `head_yaw+head_roll` 目标区间内该件对 0 条；L1 H03 支撑/悬垂不变差。

**2. 元件占位块进 placed/（§一 3、§三 8）。** 照 `build.py:49` zz_battery 的写法加 `zz_imu`（25.4×17.78×4.6，body trunk_base，板面贴 T01 前壁外侧 x −21.1，孔对 (±10.16, 111.65)，元件朝 +x）、`zz_sbc`（Radxa ZERO 3W 65×30，PCB 1.6 + 排针 8.5，body jaw_soft，孔距 58×23 对 H01 立柱，位置从 head.py 立柱坐标取）、`zz_camera`（板 32×32×1.6 + 镜座 13.2×13.2×14，脸板位置按 电子件布局_2026-09-20.md §6）、`zz_switch`（KCD1-101 本体 21×15×20 在 T02 壳顶）；UBEC 到货卡尺后再加。每个都要：`cad_geometry_manifest.json:body_for_part` 加名（hr17 教训：漏了运动审计开头就炸）、components.yaml 对应元件 `claim.placed_prefix` 指过去（同 bus_adapter → zz_adapter）。step 19 拆成逐件 motion（IMU 的装入其实在 seq 9 之前：从 +x 沿 −x 贴上前壁；Radxa −z 落立柱；开关沿壳顶法线；UBEC 缺尺寸先 unknown）。L3 静态、L6 运动、L7 质量会自动带上，不加判据。F26 从坐面量叠厚那两条红会随 zz_imu 进 placed/ 而有物可量。

**3. 顺手的数据**：disasm06 `reverse_of_step`、orig_face_part / orig_jaw 补一个装入步（present_only_installed WARN 的来源）。

## 重训前（不进 hr31/32）
生成的 MJCF 全 body 碰撞几何 + mjlab 不关 col_*（`diag/col_check.py`、`lying_pose.py` 先跑）；新策略 → `policy_envelope.py --dump-steps` → `derive_target_ranges.py` → 新目录重采。现在的目标区间和 5601 姿态都是原版策略的。

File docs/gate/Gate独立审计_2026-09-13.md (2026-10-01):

# Gate 独立审计 · 2026-09-13

审计对象：`tools/gate/`（core.py / gate.py / tool_access.py / layers/l0–l7 / negatives/ / data/*.yaml），记分卡 `tools/gate/out/scorecard.json`（09-12 18:30，build #6 的 STL，L2 重跑其余继承）。
方法：全部代码逐行静态读（我本人读 core/gate/L0/L4/L5/L5螺丝头/L6/tool_access；两个只读子 agent 分别读 L1–L3 与 L7+反例包，关键结论我复核过）；记分卡用脚本抽样与统计；**只跑了一次** `gate.py --layers 0 --out <scratchpad>`（7 分 14 秒，27 个反例全过，L0 本身几秒）。仓库里没有任何被跟踪文件被改动，只有 gitignored 的 `tools/gate/out/_neg_tmp/` 被反例包重写。
已知项（切片器丢失、tool_access 27 组 unknown、L6 工作空间、分度圆未定案、发布目录未同步）不再重复，只在相关处引用。

分级：BLOCKER = 会让"绿"变成假绿、或让"红"大面积判错地方；MAJOR = 规格承诺没兑现或判据设计有洞；MINOR = 可维护性/口径。

---

## 0. 一页结论

- **绿能不能信**：76 个绿格里，L0 的 16 个、L3 的件×件与轴承×件、L6 的 8 个单轴、L5 的 H02/L03/N01 坐面、L4 的 step01–07/10/17 这 ~45 个有真证据。剩下的绿分三类不能信：**结构性空绿**（`L2/_coverage 171/171`：12 条特征零判据却记 covered；`L1/_calibration`：三条 BLOCK 判据在标定集上 0 次实评；`L5/fits.*.fit_measured_geometry`：关系判红也算"已实测"绿）、**同源自证**（L3 KO01 用 CAD 同一把 conn_cut 刀、"元件完整实体"是 build 自家占位体；L7 `_fk` 对 kin 自洽）、**条件绿**（L4 的 step 绿只在 assembly.yaml 的 `present` 诚实时成立，没有任何独立推导）。
- **红里多大比例是判据问题**：915 条红判据中 401 条无实测数（370 数据缺、31 判据未实现）→ 不是件的问题；514 条有数的里约 204 条落在判据设计有问题的族（L5 坐面/螺丝头 78、L2 孔周壁错量纲 65、L6 全上游行程 41、L1 min_wall 16、L2 直径刻面 4）。粗算 **6 成以上的红不是件的问题**；真几何/真装配的红集中在 L6 工作空间（已知）、L2 通/盲/存在、L3 KO07、L5 咬入不足（F19/F21/F26）这几处。
- **最该先修的三件事**：① 反例包加 severity + measured 断言、补 L0/L3/L7 反例（现在两条判据降 WARN 后反例照过，"翻回 BLOCK 也没人抓"已经发生）；② 三处空绿/错红一起修：`l2_features.py:1250` 的 covered 先登记后判断、`calibrate_l1.py:62` 把 evidence_n=0 的 PASS 算 unknown、`l5_screwhead.py:292` 跳过 pilot_hole 且坐面只判头侧；③ hash 绑定补全（格级 inputs 加 `duckstructure/*.py` 与 placed/）+ `gate.py --verify` + 把硬编码 STALE 换成别的状态，否则"旧绿失效"是承诺不是机制。

---

## 1. 十条元规则逐条落地情况

| # | 元规则 | 结论 | 证据 |
|---|---|---|---|
| 1 | 查导出 STL 不查内存 | **落实** | L0/L1/L2/L5 读 `cad/duck_s288/*.stl`（l0:68、l5:491、l5_screwhead:295）；L3/L4/L6/L7 读 `placed/*.stl`（l4:75、l6:113）。但 L3 的"元件完整实体"是 build 导出的占位体，不是 datasheet 独立建的（见 F-L3-4） |
| 2 | 每个 0 带证据数 | **落实，口径不一** | core.py:258 把 evidence_n=0 的 PASS 降 NOT_RUN，记分卡实测 0 条零证据 PASS。但 L6 的 evidence_n 是"角度×件对"（l6:607，left_hip_pitch 30240）而实际布尔 287 次，AABB 排除的对也算证据；L2 凑数 INFO（l2:1364/1500 evidence_n=1） |
| 3 | 采样独立于建模角 | **落实** | `duckstructure/checks.py:8-13` 零度对齐 2.5° 网格+端点。L2 的 24/16/8 向与 64 边多边形整除（l2:51-60 vs s288.py:53），名义独立、实际相位锁定 |
| 4 | 未知=失败 | **大体落实，有吞点** | `res.unknown` 遍布；布尔失败 L3/L4/L6 都抛。吞点：l1:98-102/113-116/256-259 三处 except 往 PASS 方向吞（见 F-L1-4）；l4:172-173 `_Names` 舵机表 except pass；l7:401-404 placed 指纹失败 continue；l7:964 `home_rad` 缺省 0；l6:808 mjcf_ranges 写失败只进 detail。**框架级漏洞**：core.py:329-330 覆盖率义务在清单无 id 时静默跳过（F-核-1） |
| 5 | 不比历史 | **落实** | 层里无 prev 读取；`impact.md` 只报状态变化；L4 声明 peak_mm3 只进 detail（l4:918-933） |
| 6 | hash 绑定 | **部分** | 全局 manifest 有（core.py:119-134）；发布副本/源码副本/冻结基线三条 sha256 判据真会红（本次 L0 实跑：5 个发布 STL、6 个源码文件不一致 → BLOCK）。**但没有任何工具核对记分卡 vs 当前文件**，"hash 对不上作废"靠人眼；`git` 字段接受 `+dirty` |
| 7 | 过期标记 | **部分** | 层没跑时按格级 inputs_hash 判 STALE（core.py:279-298）。格级 inputs 漏 `duckstructure/*.py`（除 L0）与 placed/（L1/L2/L3/L5/L7），改 kin/lib/s288 不会灰（F-核-2，Codex01 FG03 未修）；`--parts` 子集跑把其它件全判红且覆盖 prev（F-核-6，FG02 未修）；STALE 被 L6/L7 当"判据退役"标签硬编码（F-核-5） |
| 8 | 反例先跑 | **落实一半** | gate.py:118-125 先跑，失败整轮 BLOCKED；27 个反例坏样本真实。但只验 state 不验 severity，unknown 与"抓到"不分；L0/L3/L7 零反例；README 举的 7 例缺 5 例（F-反-1/2） |
| 9 | 三级+豁免 | **代码对，文档错** | core.py:157-170 只 WARN 可豁免、绑定必须非空且逐项匹配。但 waivers.yaml:29-34 写的绑定 schema 与代码要的 key 不同，按文档写的豁免永远被拒（F-核-4）；豁免 id 可只写到格子（core.py:153-154），会豁免整格所有 WARN 判据 |
| 10 | 性能 | **未达** | 全跑 1795 s，反例包约 430 s，L2 约 800 s；build ≈ 8 min → 目标 ≤ 4 min，实际 7.5×。无跨轮内容 hash 缓存；单件不能独立跑（F-核-6） |

---

## 2. 逐条 finding

### 2.1 内核 / 入口（方向 1）

**F-核-1 [BLOCKER] core.py:326-330 + data/assembly.yaml** — L4 装配步覆盖率义务静默失效。
证据：`want = {x["id"] ...}; if not want: continue`；assembly.yaml 19 步 **0 步有 `id` 键**（脚本核对），所以 `L4/_coverage` 格从未存在（记分卡确认无此格），l4:828 的 `res.covered.add(str(st.get("id", n)))` 登记的是 `"None"`。COVERAGE_ITEMS 是元规则 4 的框架级落实，它自己却在数据缺 id 时"静默跳过"。
建议：`if not want:` 改为写一条 FAIL 格（"清单条目无 id，覆盖率无法计算"）；assembly.yaml 每步补 `id`。

**F-核-2 [MAJOR] core.py:248-253, 367-372** — 格级 `inputs_hash` 不含 `duckstructure/*.py`（除 L0）和 placed/（L1/L2/L3/L5/L7）。
证据：记分卡各层 inputs_hash 键统计：L1 无 duckstructure、无 placed；L3 52 个 placed 但无 duckstructure/MJCF（L3 读 `lib.conn_cut`、`s288.S.horn_r`、`kin`）；L5 32 个 STL 无 duckstructure；L7 18 个导出件无 placed（L7 的世界质心、舵机/电池/轴承实体全读 placed）。`SOURCE_GLOBS` 的 `cad/duck_s288/*.stl` 非递归。后果：`retarget_horn_r` 改 s288.py 后只重跑 L2，L3/L5/L7 格子按"输入未变"沿用旧绿。
建议：`implicit` 加入 `duckstructure/*.py`（已在 SOURCE_GLOBS，只差进格）；各层 `res.inputs` 补它实际打开的 placed 文件；L3 加 lib.py/s288.py/MJCF；L7 加 kin.py/checks.py。

**F-核-3 [MAJOR] gate.py:167, core.py:391** — `source_manifest` 只写进记分卡，没有反向校验入口。
证据：grep 全仓库，`source_manifest` 只在生成时使用；README 元规则 6"hash 对不上的记分卡作废"没有执行者。09-12 的清红记录"137 个格子输入文件 hash 全部匹配磁盘"是人工脚本核的。
建议：`gate.py --verify [scorecard.json]`：逐格 inputs_hash 与磁盘 sha256 比、git HEAD 比、dirty 判 INCOMPLETE；退出码非 0。

**F-核-4 [MAJOR] data/waivers.yaml:29-34 vs core.py:162-167** — 豁免绑定 schema 与代码不一致。
证据：文档要求 `bound_input_hashes: {duck_py_sha256, s288_py_sha256, robot_walk_xml_sha256, stl_sha256: {件号: hash}, data_yaml_sha256: {文件名: hash}}`；代码 `changed = [k for k,v in bound.items() if manifest.get(k) != v]`，manifest 键是仓库相对路径 → 文档格式的每个键都 `manifest.get(k) is None ≠ v` → 永远失效。反例 `n_core_waiver.py:25-29` 用的是路径键，所以测不出文档错。另 core.py:153-154 接受 `L5/X`、`X.5` 这种不带 check 名的 id，会豁免该格**全部** WARN 判据。
建议：waivers.yaml schema 改为 `bound_input_hashes: {<仓库相对路径>: <sha256>}` 并写明至少绑定本件 STL + 12 个 yaml；`apply_waivers` 只认带 check 名的 id。

**F-核-5 [MAJOR] l6_motion.py:444, 514, 1148；l7_mass.py:816, 893 vs core.py:25, 296** — `state=STALE` 硬编码当"判据退役"标签。
证据：core 里 STALE = "输入变了没重跑"，由继承逻辑恢复；这五条永远灰，任何输入都救不回 → `verdict` 永远 ≠ CLEAR（core.py:381），退出码永远 ≥ 2；且 `tally[STALE]` 不再能回答"哪些格子过期了"。
建议：改 `res.unknown(..., severity=WARN)` 或新增状态 `RETIRED`（不计入 INCOMPLETE）。

**F-核-6 [MAJOR] gate.py:127 + core.py:302-324** — `--parts` 子集跑不可用；`scorecard.prev.json` 被子集跑覆盖。
证据：层在 `ctx.only` 外的件不发 finding → obligations 循环对本轮跑过的层写 `obligation_unmet` FAIL（"该层跑了，但没有为这个对象发出任何判据"）；gate.py:198 无条件写 prev。本次实跑 `--layers 0`（无 prev）：266 格里 242 格 obligation_unmet。README 元规则 7"改一个件只重跑受影响子集"没有实现（Codex01 FG02 未修）。
建议：同层、不在 `ctx.only` 的格子按 inputs_hash 继承（与跨层继承同一逻辑）；`--parts`/`--layers` 子集跑不写 prev，或写到 `scorecard.partial.json`。

**F-核-7 [MINOR] gate.py:178-185** — `L0/_negatives` 红格没有 inputs_hash，之后任何不含 L0 的子集跑都会把它按"输入未变"继承，反例修好也留红。
建议：反例结果无论过不过都写一格，inputs = `tools/gate/negatives/*.py` + 各层文件。

**F-核-8 [MINOR] core.py:205-228 obligations** — 义务清单与层的适用范围不对齐，制造 4 个永久红：`L4/F21b_B01_rear_disabled`、`L4/F27_zip_xt30`、`L4/F28_snap_B01`（tool_access.py:39-40 对非螺丝 `continue` 不发 finding）、`L6/mouth`（frozen 15 条关节，`exists_as_mjcf_joint=false` 在 l6:413-415 被跳过）。
建议：跳过时发一条 `PASS INFO evidence_n=1 "不适用"`（l5_screwhead.py:240 已经这么做），或 obligations 按 `joint_type`/`exists_as_mjcf_joint` 过滤。

**F-核-9 [MINOR] gate.py:118-125** — 反例包每次 ~7 分钟（本次实测 L0 全程 7:14，L0 本身几秒），任何 `--layers N` 调试都付这笔；`--skip-negatives` 又让整轮 BLOCKED。
建议：反例结果按 `sha256(negatives/*.py + layers/*.py + core.py + data/*.yaml)` 缓存到 `out/negatives.cache.json`，命中直接采信。

### 2.2 各层判据（方向 2）

#### L0 网格与坐标（l0_mesh.py）

- **[MINOR] l0_mesh.py:63, 126** — 量级阈值 `3..300`、整机 `50..400` 写死在层里；`assembly_bbox_scale` evidence_n=1，算出来的 `sites` 只进 detail 不参与判断（l0:122-131）。`_datum/datum_vs_mjcf` 诚实 unknown（l0:224），基准落位这条 README 判据至今没实现。
- **[MINOR] l0_mesh.py:19-21** — `hole_edges` 等用 `duckstructure.lib.stl_stats`，与建模代码共享实现，不独立。
- 正面：`_release`/`_frozen` 三条 sha256 判据在当前工作区真的红了（本次实跑：`export_vs_release_sha256` 不一致 L01/L02/N02/H01/H03，`source_copy_sha256` 6 个 .py 不同）。

#### L1 可打印（l1_printable.py；子 agent 读，关键点我复核）

- **F-L1-1 [BLOCKER] l1_printable.py:549-566 + calibrate_l1.py:62-69** — `_calibration/proven_parts` 是零实评的绿。
  证据：`data/l1_calibration.yaml` 里 `min_wall_sliced / support_model_brackets_slicer / support_in_no_support_zone` 三条 BLOCK 判据 **n_eval: 0**；唯一 n_eval=8 的 BLOCK 判据 `min_hole_dia` 是标定用空 features 喂出来的"本件没有声明任何孔类特征"PASS（evidence_n=0，记分卡里会被 core 降 NOT_RUN，但 calibrate_l1.py:62 只按 criterion 文本认 unknown，计成通过）。CHANGELOG 09-13 "BLOCK 判据 0/8 → 绿"就是这个。
  建议：calibrate 把 `state==PASS and evidence_n==0` 计 unknown；范围内 BLOCK 判据 `n_eval==0` → `_calibration` 必须 unknown；反例 `n_l1_calibration_record.py` 补"全部 n_eval=0 必须红"。
- **F-L1-2 [MAJOR] l1_printable.py:250-257, 587-591** — 标定只统计 BLOCK 判据，判据一降 WARN 就从标定门禁里消失；`min_wall_geometric`（5/8=0.625 > 0.5）、`support_reachable`（4/8）现在都不触发。标定样本本身（他人打出来的原版件）是合法证伪样本，不算循环；循环的是"谁红就把谁踢出去"。
  建议：`checks_in_scope` 内不分 severity 统计，WARN 超限发 WARN 级 finding。
- **F-L1-3 [MAJOR] l1_printable.py:1090-1094** — "支撑下界已超 → 一定有支撑进禁撑区"依赖 `sm_lo` 是真下界，记分卡 `L1/N04 support_model_brackets_slicer` 已证伪（切片器支撑挤出 0.0，模型下界 19.4）。9 条"下界超"红里小数值的（L04 0.116、T03 0.539）大概率同类。
  建议：`support_in_no_support_zone` 判红前要求本件 bracket 判据 PASS，否则 unknown；豁免②锚点判据用包围角不用连通块数。
- **F-L1-4 [MAJOR] l1_printable.py:98-102, 113-116, 256-259** — 三处 `try/except` 往 PASS 方向吞：层多边形化失败 → 该层"没料"；`_thin_regions` 失败 → `return 0,0.0,0.0`（无薄壁）；支撑差集失败 → `u=None`（该层全被托住）。只有 `all(p is None)` 才 unknown（l1:722）。
  建议：记 `n_layer_failed`，>0 时 `min_wall_geometric / support_* ` 全部 unknown。
- **F-L1-5 [MAJOR] tools/gate/slicing/slice_l1.py:165** — `min_wall_sliced` 的单 bead 比值 0.75 写死在切片解析脚本里，printability.yaml 无此键，标定集对它 n_eval=0。现在唯一的 BLOCK 墙数判据从未在好件上验证过（L03 74/142 那条红是它上一版解析错误的产物，已知）。
  建议：阈值进 `printability.yaml:criteria.single_bead_ratio_max`，标定集补切片。
- **[MINOR]** `min_hole_dia`（l1:843-886）判 yaml 声明值不判 STL；09-13 retarget 后 40 条 `nominal_d_mm` 仍标 `src: measured`（值 2.4，量到的是 2.2）。`print_orientation/slice_freshness` evidence_n 硬编码 3/2（l1:684/700）。inputs 未声明 `slicing/slice_run.yaml`、`slicing/logs/*_profile.ini`、`calibrate_l1.py`。`P.get("_calibration_inner_run")`（l1:1167）是从 yaml 可注入的旁路。

#### L2 特征存在（l2_features.py）

- **F-L2-1 [BLOCKER] l2_features.py:1250 + 1287/1548** — 12 条特征零判据却登记 covered，`L2/_coverage 171/171 PASS` 是假的。
  证据：`res.covered.add(fid)` 在任何判断之前；之后只有 `if cyl_u:` 与 `if box_u and not cyl_u:` 两支，两者都空时无 else。记分卡核对：`L01-F11, L01-F13, L02-F08, L03-F05, L04-F12, L05-F08, L06-F01, N01-F09, N02-F10, H01-F13, H03-F05, H03-F06` 在 L2 一条 finding 都没有。其中 L01-F13/L03-F05 已有 `box_export_local`，但 L2 的 `BBOX_KEYS`（l2:558）不认这个键（L1 认）。
  建议：分支后加 `else: res.unknown(pid, f"{fid}:geometry", ...)`；`covered.add` 移到发出 finding 之后；`BBOX_KEYS` 加 `box_export_local`。
- **F-L2-2 [MAJOR] l2_features.py:1338 + ring_scan:697-713** — `diameter` 的 measured 是射线命中半径的中位数（内接），被 64 边刻面系统性压低；遇到 `target_range.min == nominal` 的桶必红。
  证据：记分卡 4 条 `:diameter` 红全部落在刻面误差内：L01-F02 Ø14.846 vs 声明 14.85（Δ0.004，64 边内接上界 0.018）；L01-F10/L03-F04 Ø27.1209 vs 27.15（Δ0.029，上界 0.033）；T01-F25 Ø21.1274 vs 21.15（Δ0.023，上界 0.026）。`duckstructure/s288.py:53` 默认 sections=64。`bore_gauge` 自己在 l2:725-731 说明了刻面偏差并用棱边规避，`diameter` 没有。
  建议：diameter 的 measured 改用 bore_gauge 的"棱边最近点"，或按 `r/cos(π/N)` 修正；否则这 4 条红全是判据问题。
- **F-L2-3 [MAJOR] l2_features.py:1502-1545** — `:wall` 用结构墙 2.5 判孔周壁厚，代码自认量纲不对，记分卡 66 条 WARN 红（70 条里 66 红）。
  建议：tolerances.yaml 增 `hole_wall_thickness` 桶（标 assumed），没有就 unknown(INFO)。
- **F-L2-4 [MAJOR] l2_features.py:1636-1658** — `min_section` 沿 bbox 最短轴逐列量，非矩形板的 AABB 空角报 0.0（B01-F01、T01-F02、T01-F09 三条 0.0 红）；容差借 `hole_depth_mm.min`。
  建议：只统计 `n_keep>0` 的列；空列另发"bbox 与板轮廓不符"WARN。
- **F-L2-5 [MAJOR] l2_features.py:1723** — 镜像轴 `M=[1,-1,1]` 写死；parts.yaml 只有自由文本 `mirrored_copy`。
- **F-L2-6 [MAJOR] data/features.yaml（54 条）** — `nominal_d_mm src: measured` 是"射线量导出 STL"得来的，再拿去对同一份 STL 是循环；present/diameter 对这些条目只证明"STL 没变"。retarget 后 40 条的 2.4 既非量得也非旧值。
  建议：nominal 的 src 指向 duckstructure 常量（design/assumed），量得的数放 `frames.verification`。
- **[MINOR]** 盲深多实例只拿 `blind[0]`（l2:1477）；`wall` 只查 `scans[:8]`（l2:1515）；`probe_units` 坏实例静默丢（l2:591）；`through` 的 dead 实例不判（l2:1416-1470）；采样向 24/16/8 与 64 边整除（l2:51-60）；`pitch_radius`（l2:1697-1705）两边都来自 s288.py:horn_r，分度圆未定案前这条绿证明不了任何事。

#### L3 静态装配（l3_static.py）

- **F-L3-1 [MAJOR] l3_static.py:105-120** — 禁入体圆柱用外接 128 边形（`r/cos(π/128)`），STL 孔是内接 64 边形；0.05 mm³ 阈值低于刻面噪声。`L3/H01 keepout_KO09 0.7211 mm³`（Ø4.6×40 通道）落在刻面量级；KO07 7.44 mm³ 部分同源。交接文档 §8-7 自己也把 KO07/KO09 根因归到"lib.cyl 64 边内接 vs Gate 128 边外接差 0.011/0.0035"。
  建议：禁入体圆柱按 s288.cyl 同段数同相位建，或 keepouts.yaml 给 `facet_noise_mm3`。
- **F-L3-2 [MAJOR] l3_static.py:394-405** — KO01 插座走廊直接 import CAD 开窗用的 `duckstructure.lib.conn_cut(sfw(n,i))`，载体×自家走廊 = 0 是构造保证；geom_verbatim 里 6.6×9.2 窗面与插头本体没有独立实体。
- **F-L3-3 [MAJOR] l3_static.py:748-781** — "打印件 × 元件完整实体"查的是 build 导出的 placed 占位体（servo__*/bearing_*/zz_battery），components.yaml 的 envelope 只用来认领（l3:217-242）；载体对自家舵机的 0 同样是 servo_env 挖过的构造保证。带头螺丝诚实 unknown（l3:784）。criterion 应写明"实体与 CAD 同源"。
- **[MINOR] l3_static.py:334-528, 808-811** — KO 编号、`"B01"` 豁免（l3:502）、`neck_pitch/head_yaw`、`z0,z1=100,175`、`300×200` 盒、`servo__/bearing/orig_` 前缀全部写死；KO15 光轴 `+x` 写死（l3:544，Codex01 FG16 未修，代码自述"不是可机读的数据"）。`_DEFERRED` 5 条 NOT_RUN INFO（l3:829-836）与 obligations 冲突 → 永久 INCOMPLETE。件级 `evidence_n=len(rows)` 是超阈对数不是查过的对数（l3:770/898）。
- 正面：布尔失败全部进 `boom` → unknown，不吞成 PASS；双层 AABB 粗筛。

#### L4 装得进去（l4_assembly.py + tool_access.py）

- **F-L4-1 [MAJOR] l4_assembly.py:553-600 (`judge_fixed_path`) + 603-623 (`motion_coverage`) + tool_access.py:91-95** — 工位在场全集 `present` 完全自报，唯一交叉核对是同一文件里同一个人写的 `required_motion_groups`。没有从 `already_installed`/子总成关系推导最小 `present` 的逻辑。
  证据：脚本对 36 条 motions 核对，`present` 与步骤 `parts/already_installed` 的差集普遍非空（这是"工位"设计的本意，但意味着少写一个障碍不会被任何判据发现）；tool_states 24 个 `present` 同理。所以 L4 的 step 绿是**条件绿**。
  建议：判据补一条 `present ⊇ movers ∪ resolve(parts[1:]) ∪ resolve(already_installed ∩ 本工位子总成)`，子总成归属在 assembly.yaml 只声明一次（`subassembly_of`），差集非空 → BLOCK。
- **[MINOR] l4_assembly.py:172-173** — `_Names.__init__` 舵机表 `except Exception: pass`；旧格式步骤里认不出的词只在 `_names/unresolved_tokens` 记 WARN（l4:1190），但那是"障碍从集合里消失"，应 BLOCK。现在 19 步里 18 步已迁到 motions，只剩拆卸序（B 段）用 `names.resolve`，且拆卸障碍用整机 `geo.index`（l4:1123），风险有限。
- **[MINOR] l4_assembly.py:1093-1098, 1125** — 拆卸序移动件靠 action 文本启发式（`"舵机" in act`、件号子串）挑，挑错会扫错件；拆卸沿用 `judge_step_path` 两个符号都试、没有 `step_direction_declared` 对应项。
- **[MINOR] l4_assembly.py:326, 516** — 扫掠是 0.25 mm 步距采样不是扫掠体；薄板穿薄壁（两者沿 d 总厚 < 步距）理论上会漏，criterion 里应写明采样性质。
- **[MINOR] tool_access.py:128-129** — `if host != stems[0]: world[1] *= -1` 镜像约定写死。
- 正面（核过的）：`_proven_clear_after`/`_proven_clear_at`（l4:390-414, 530-550）两条证明都用 AABB 支撑区间，AABB 分离 ⇒ 网格分离，方向正确，证不出就 FAIL，严密。`seat_samples`（tool_access.py:20-29）在 3 圈×24 向足印上 ±0.001 mm 内/外探针，内全有料外全为空，量的是真坐面。`screw_head_visible` 射线用的是 present 合并网格（tool_access.py:160-163）。
- 注：记分卡里 `L4/step08` 红是 build #6 时 step 8 还是 `axial_press` 无路径；现在 10 条 motions 已声明但未跑，预期变化。

#### L5 功能达成（l5_function.py + l5_screwhead.py）

- **F-L5-1 [MAJOR] l5_screwhead.py:265-266, 292-341** — 对 `feature_hole_map` 里**所有**孔（含 `pilot_hole` 接收孔）做头判据；接收件上根本没有头。
  证据（记分卡）：`L5/F24_L07_to_L05 stack_from_seat_crosscheck` 逐孔 `[5.3,5.3,5.3,5.3,2.544,31.491]`，后两个是 L05-F12（L05 上的 Ø1.6 底孔）→ `engagement_from_measured_seat = −19.491 "顶死"` BLOCK；`F19 head_seat_flatness` 最差 H01-F12（H01 底孔）9.75；`F20 stack_from_seat_crosscheck` 最差 T01-F23（底孔）12.16；`F21` 最差 T01-F16（底孔）。23 条螺丝头红里 4 条最差孔是底孔；反过来 F19 的 `engagement_from_measured_seat 4.0 PASS` 也是从接收件量的（错孔上的绿）。
  建议：l5_screwhead 复用 l5_function `_group_holes` 的 thru/recv 分类，只对 thru 做头判据。
- **F-L5-2 [MAJOR] l5_function.py:488-513 + l2_features.py:342 (seat_profile "返回较差的那一端") + l5_screwhead.py:328** — 坐面判"较差的一端"，不知道头在哪边。
  证据：19 条 `seat_flatness:hole*` 红里 11 条一端 ≤ 0.3、另一端 1.75–35.3（T01 hole0/1：两端 [0.0, 9.9]、叠厚 5.8..15.7；L07、T02、B01、L05 同）—— 头侧平、远端有台阶就红。且 `_screw_holes`（l5:148-153）把件上所有 Ø(m_through±0.1) 孔当螺丝孔（扎带孔、过刀孔一起判）。
  建议：头侧方向从 `fasteners.yaml:tool_access[].seats[].outward_export_local`（F01/F24 已有）或 `drive_direction` 取；取不到 → unknown，不取较差端。孔集合按 `feature_hole_map` 而不是按直径扫全件。
- **F-L5-3 [MAJOR] l5_function.py:814-816** — `measured_buckets[path] = rid` 不看 `relation_contact` 结果 → `fit_measured_geometry` PASS(BLOCK)。
  证据：9 个"已实测"桶里 4 个的关系判红：`fits.deck.keyhole`（R21 FAIL −0.51）、`fits.pla.bearing_axial_retention`（R03 FAIL）、`fits.pla.plain_slide_head_roll`（R11 FAIL −0.098）、`fits.servo.back_clamp`（R08 FAIL −0.3）。这些桶格里剩下的红只有 `fit_on_placeholder` WARN → 可豁免 → 桶格可以变绿而关系是红的。
  建议：只在 `relation_contact` PASS 时登记；或把这条改名 `geometry_was_measured` INFO。
- **F-L5-4 [MAJOR] data/tolerances.yaml + l5_function.py:919** — 阈值本身的 src 没有进判据：31 个 fits 桶 `target_range_mm` 一个都没有 `src`；`feature_check_tolerances` 8 键里 7 键无 src、`seat_flatness_spread_mm` src=assumed（"本文件提出的阈值"）；`fit_on_placeholder` 只是 WARN（可豁免）。元规则 4 只覆盖"值是 assumed"，不覆盖"阈值是 assumed"，于是对着拍脑袋阈值的 BLOCK PASS 与对着实测阈值的 PASS 在记分卡上没有区别。
  建议：target_range/feature_check_tolerances 加 `src`；层把阈值 src 写进 finding，阈值 assumed 时 PASS 降 NOT_RUN 或 severity WARN。
- **F-L5-5 [MAJOR] l5_function.py:136-144 `_blind_depth`** — 自攻盲深从 `joins/location` 自由文本正则抠，不读 09-09 起就有的机器可读 `pilot.pilot_depth_mm`。
  证据：F26 文本写"Ø1.7 深 10"，`pilot.pilot_depth_mm = 3.5`，yaml 自己注明"这条文本是错的"；`_blind_depth` 会返回 10 → `screw_length_rule` 上限放宽 6.5 mm（当前因 stack 未知而 unknown，是潜在假绿）。
  建议：先读 `pilot.pilot_depth_mm`，没有才退回文本并标 detail。
- **[MINOR] l5_function.py:321-322** — `fits.pla.m2_through_hole / m2_counterbore` 桶路径写死（材料/规格）；l5_screwhead 已按 spec 泛化，两个模块口径不一致。
- **[MINOR] l5_function.py:667-668** — 舵盘 `pattern_radius` 的声明值从 `nominal_source.v` / `spec_verbatim` 文本正则抠 `r4.75`，不读 `geom.pitch_r_mm`；`retarget_horn_r.py` 只改坐标与 `pitch_r_mm`，不改文本 → 定案 Ø10.5 后这条会拿旧 4.75 判新 STL → 假红。
- **[MINOR] l5_function.py:569-606** — `engagement_per_hole` 逐 thru 件各自算 `L − 该件叠厚`，穿两件的组（F19 H01+H02、F20 T01+T02+T03、F24 L05+L07）每行都高估咬入；F24 因 L05 侧孔关联不上碰巧未触发。
- 正面：`contact_profile`（l5:244-303）真量有符号配合量/接触面积/夹紧行程，`sign_convention` 不声明就 unknown；`engagement_per_hole` 最浅/中位/最深三量各判；`fit_value` 对 assumed nominal 只记 INFO——这三处设计是对的。22 个 `fits_on_placeholder` 桶每个都有 `fit_on_placeholder` FAIL(WARN) + 未实测的还有 `fit_measured_geometry` FAIL(BLOCK)：**诚实地红了**，只是 WARN 可豁免这一点与 F-L5-4 叠加要小心。

#### L6 运动（l6_motion.py）

- **F-L6-1 [MAJOR] l6_motion.py:635-662** — 两两组合用 `max(10°, 量程/12)` 粗网格（±90° 关节 = 15°），只在**最差的粗格**附近加密到 2.5°；粗网格没命中的组合碰撞口袋（两轴都非零、宽度 < 网格）完全看不见 → `pair_combination` 可假绿。Codex01 FG19 未修。
  建议：对所有粗格命中加密，并对 `min_gap < gap_tol` 的粗格也加密；或统一 5°。
- **F-L6-2 [MAJOR] l6_motion.py:203-219** — `mating_pairs` 把零位姿间隙 < 0.3 的**任何**件对自动豁免出运动最小距离判据（记分卡 `L6/_zero`：37 对）；非配合面的 0.1 mm 零位间隙也被当配合面。Codex01 FG18 未修。
  建议：豁免只认 relations.yaml 里声明的 `contact.parties`。
- **F-L6-3 [MAJOR] l6_motion.py:605-607, 674, 748, 812, 1199** — 层的 docstring（l6:23-24）说上游区间"只当扫描候选域，不当放行依据"，但 `single_axis_sweep`/`pair_combination`/`motion_collision`/`collision_buckets` 对全上游行程内任何一条碰撞记录判 BLOCK；`collision_free_range` 只要需要收窄就 FAIL(BLOCK)；`combo_collision_inside_free_range` 1166 条。这四类共 41 条有实测数的红在"控制端限位"方案下是**工作空间问题不是件的问题**，但记分卡把它们判成件级 BLOCK（`motion_collision` 落到 17 件格子上）。
  建议：数据里声明目标区间（`frozen.yaml:joint_axes[].target_range_deg` 或读 `sim/duck_s288/robot_walk_s288.xml` 的 `<joint range>`），区间内碰撞 BLOCK、区间外 WARN；`collision_free_range` 改判"生成的 MJCF 的 range ⊆ 本层收窄区间"（不是同义反复：那份 XML 是独立产物，会过期）。
- **[MINOR] l6_motion.py:514, 713** — `policy_extreme_poses` 对着 STALE 的旧策略包络判 BLOCK；"策略包络内"那档没有被当成"只有它才算"（全行程都 BLOCK），问题反而是包络本身过期。建议重训导出前降 WARN。
- **[MINOR] l6_motion.py:223-255** — 切刀区间从 frozen.yaml 一句自然语言正则解析（层已自报 `_cutter/cutter_domain_declared` WARN）；`_CUTTER_LABELS` 标签→关节表写死。
- **[MINOR] l6_motion.py:1207-1223** — 线束 9 束永远 unknown（数据无折线），诚实红。
- 正面：`check_angles` 零度对齐独立网格；`_Scene.evaluate` 布尔失败抛 ValueError；`collision_geom_coverage`（l6:1089-1116）对着**自己生成的** MJCF 判可达域内碰撞是否可见，且注明 single 档恒 0 不是判据功劳——这条设计得很清醒。

#### L7 质量与力（l7_mass.py；子 agent 读）

- **F-L7-1 [BLOCKER] tools/gate/negatives/（缺）** — L7 没有任何反例（`grep -l "l7_mass\|LayerResult(7"` 只命中 n_core_severity 的桩）。12 类 BLOCK 判据（`mirror_body_pairs / zero_pose_consistency / joint_axis_assumption / inertia_tensor_parsed / forcerange_* / static_torque / com_in_support_home / rib_* / load_path_*`）一条都没证明过自己会红。
- **F-L7-2 [MAJOR] l7_mass.py:1154-1155** — `inertia_tensor_parsed` `state=PASS if n_I else FAIL`，criterion 写"每个 <inertial> 必须给出惯量张量"，15 个 body 有 1 个就绿（同类错误 `forcerange_inventory` 在 l7:277-281 已修过）。
- **F-L7-3 [MAJOR] l7_mass.py:984-1016** — `static_torque` 只判单轴扫描峰值，home 姿态扭矩 `th` 算了不判；`lo>hi` 区间反转不校验（check_angles 只返回两端点，evidence_n=2 也能 PASS）。
- **F-L7-4 [MAJOR] l7_mass.py:1328-1329, 1363, 1015** — `com_in_support_home`/`static_torque` PASS(BLOCK) 不与质量清单缺口联动：15 类元件无质量、4 条 `component_body` 红、2 条 `world_placement_for_mass` 红时，整机重心/扭矩仍是绿 BLOCK，detail 里才写"缺头部电子件"。头部件力臂最长，缺它们的结果是下界。
- **F-L7-5 [MAJOR] l7_mass.py:123-127 vs 211-213** — 额定扭矩读两个键（`servo_output_bearing.rated_stall_torque_Nm` / `servo_rated_torque_Nm.stall_torque_Nm`），yaml 自己写"唯一权威在后者、前者要删"，两处不一致无人报警。用的是三个数里最宽松的 0.6 N·m 名义堵转，但"堵转≠持续"作为独立红格留着（l7:324-345），诚实。
- **F-L7-6 [MAJOR] l7_mass.py:589-653** — 元件认领按 category 写死（servo→MJCF geom、battery/bearing→envelope 正则、`cid=="original_prints"`→`orig_`）；board/imu/camera/other 无规则，有质量也进不去；`qty` 从不校验。换件必改代码。
- **[MAJOR] l7_mass.py:706-707** — inputs 只有 18 个导出件，placed/ 与 kin.py/checks.py 不在（并入 F-核-2）。
- **[MAJOR] l7_mass.py:816, 893** — STALE 硬编码（并入 F-核-5）。
- **[MAJOR] l7_mass.py:1664, 1690** — 筋厚/筋长 vs 声明 ±0.1 写死；**l7:393** 镜像对数 `== 5` 写死；**l7:964** `home_rad` 缺省当 0；**l7:401-404** placed 指纹失败 `continue`（非打印件实体静默消失）；**l7:495-531, 1301** 密度 1.27 与稳定裕度 3.0 都是 assumed，不产生任何 finding。
- **[MINOR]** `"TPU" in material` 推落地件（l7:1290）；`except Exception: pass`（l7:241）；`region_scan` 沿厚度轴不受 bbox 约束（l7:1602-1650）；0.6 的出处文档不在 inputs（l7:946-947）。

### 2.3 数据（方向 3）

- **F-数-1 [MAJOR] data/frozen.yaml** — 14 个顶层组里 `imu_pose`、`h01_sbc_posts`、`C6_interface_budgets`、`C5_reference_only`、`misc_frozen` **没有任何层读**（grep 全部 layers/*.py、tool_access.py、core.py）；`battery_bay_26` 只有 `BX0` 被 L3 用来拆 KO12（l3:494-516），26 条冻结尺寸本身不核；`P_dict` 只用 `m2_head`。README 把"躯干 IMU 位姿"列为冻结项，实际是纸面冻结。
  建议：L3 加 `frozen_imu_pose_vs_cad`（IMU 元件 placed 实体 / T01 的 IMU 座特征 vs `imu_pose.our_mounting_pos_mm`）、`frozen_battery_bay_26`（逐条对 T01 STL 射线量）；L2 加 `h01_sbc_posts`（4 立柱孔距/直径）。
- **F-数-2 [MAJOR] data/tolerances.yaml** — 见 F-L5-4：target_range 无 src、阈值无 src。22 个 `fits_on_placeholder` 桶的处理是诚实的（WARN + 未实测 BLOCK），但 WARN 可豁免 + 阈值无 src 叠加后，一个桶可以在"名义 assumed、区间无来源、关系判红"的情况下靠豁免变绿（F-L5-3）。
- **F-数-3 [MINOR] spec_verbatim** — L2 只进 detail（l2:1252）合规；L5 用它抠舵盘半径当判据（l5:668，见 L5 MINOR）；L3 用 keepouts 的 `geom_verbatim` 正则解析尺寸当判据（l3:367-568）——那是禁入体的声明本体，可接受，但 KO15 出瞳/FOV 从 `name` 字段解析（l3:522-572）太脆。
- **F-数-4 [MINOR] data/features.yaml** — 54 条 `nominal_d_mm src: measured` 循环（F-L2-6）；`clock_phase` 8 条 `not_selected` → `horn*:clock_phase_vs_declared` 永久 unknown（诚实）；`L06-F04`/`H03-F02` unresolved 诚实。

### 2.4 反例包（方向 4；子 agent 读，结论我采信并补了运行实测）

- **F-反-1 [BLOCKER] negatives/_harness.py:134-150 + 23 个层级反例** — 只验 `state==FAIL`，不验 severity，也不区分"抓到缺陷"与"算不出来"（`res.unknown` 同样是 FAIL）。**已经发生**：`min_wall_geometric`（l1:791）和 `support_reachable`（l1:1129）09-12 降 WARN，`n_l1_thin_wall.py:59` / `n_l1_overhang.py` 照过（CHANGELOG:96"复跑通过"），EXPECT 字符串仍写着阻断级红。
  建议：`_harness.assert_red(findings, check, severity, require_measured=True)`；每个反例声明期望 severity；runner 校验。
- **F-反-2 [BLOCKER] negatives/（缺）** — L0、L3、L7 零反例；L6 只有场景清单反例（无扫掠反例）。README 元规则 8 举的 7 例：空刀、轴承只查截面、扫掠区间反、螺丝加长 2 mm、单位错成米 **5 例没有**；"删一个件"只到 `placed_instance_map` 拒绝这一层。
- **F-反-3 [MAJOR]** `n_l1_missing_array_member / n_placed_instances / n_l2_nonfinite_mirror / n_l4_segment_end_inside / n_l5_self_tap_radial / n_l6_scene_inventory` 6 个只测辅助函数返回值，不经过 `run(ctx)`；函数改名/不再被调用时反例仍绿。
- **F-反-4 [MAJOR] negatives/runner.py:37-58** — 不校验 `expect_red_check` 与实际 finding 对应（`return {"passed": True}` 的空壳也算过）；无超时；不把 negatives/ 插 sys.path（standalone 跑靠加载顺序）。所有层级反例绕过 `build_scorecard`/`apply_waivers`，严重级门控/evidence_n 降级/豁免失效在层反例里没走到。
- **F-反-5 [MAJOR] negatives/n_l1_calibration_record.py:49-51** — 环境缺 upstream 网格 → `passed=False` → 整机 BLOCKED，环境判定混进检查器自证。
- **F-反-6 [MINOR]** 反例包每轮约 7 分钟（实测），无缓存（F-核-9）；README 首行"坏样本尚未生成"、_harness docstring"6 个反例"过时；README 事故表无文件名列。
- 正面：坏样本都是历史事故的最小复刻（缩径、掏空、槽挪 1 mm、等厚斜面、远壁封刀路、多段路径），带"好样本必须绿"对照，用真 tolerances 做阈值，合成网格写文件再读回（守元规则 1），不依赖切片器，runner 把异常/缺字段一律算失败。

### 2.5 记分卡抽样（方向 5）

**10 个绿格**

| 格 | 判据/证据 | 能信？ |
|---|---|---|
| L0/T01 | hole_edges 0 / 21284 面；single_solid；bbox 94.7 | 能 |
| L0/_release | 18 件 sha256 一致（09-12 时） | 能，且本次实跑已变红（build #7 后 5 件不一致）|
| L3/L01 | part_vs_part 48 对交集 0 | 能（AABB+manifold 布尔）|
| L3/KO15 | 4941 射线 0 遮挡 | 条件：光轴 +x 写死、出瞳与 MJCF site 差 (7.6, 0.1, 12.9) mm，换件/换姿态不跟随（FG16）|
| L3/bearing_6704zz | 100 对完整实体 × 打印件 0 | 能，但实体是 build 占位体 |
| L4/step06 | 2 条 motion 242 次布尔各 0、末端脱离已证 | 条件：`present` 只有 `[servo, yaw2roll]`，靠 yaml 诚实 |
| L4/disasm01 | shell_L +y 0 / −y 2366，51 障碍 | 能（拆卸用整机做障碍）|
| L5/H02 | 4 孔叠厚 5.6 极差 0、平面度 0 | 能 |
| L5/fits.servo.pad_contact | fit_measured_geometry PASS ← R17 relation_contact PASS（接触 27.89 mm²） | 这一格能；但同一判据在 4 个关系判红的桶上也 PASS（F-L5-3）|
| L6/left_hip_pitch | 72 角×420 对，287 次布尔，0 碰撞 | 能（单轴）；evidence_n 30240 是角×对不是布尔数 |
| L7/_fk | 15 body 零位 FK 与 kin 一致 | 是自洽检查不是物理判据 |
| L2/_features | 171/171 geom.frame=export_local | 能；但同层 `_coverage 171/171` 是假的（F-L2-1）|

**10 个红格**

| 格 | 红的原因 | 红得对不对 |
|---|---|---|
| L1/L03 min_wall_geometric / min_wall_sliced | 23/169 层放不下 2 圈；74/142 单圈 | 前者已按标定降 WARN；后者是切片解析误报（已知、已修未跑）→ **判据问题** |
| L2/L01 L01-F02:diameter | Ø14.846 vs [14.85,14.95] | 64 边刻面 Δ0.004 → **判据问题** |
| L2/L01 L01-F09 present/depth | Ø4.2 沉 1.25 实测掏空 0.2048 | 真数据问题：CHANGELOG 记"有效沉孔是原版 Ø4.84，我们的 Ø4.2 刀全落在里面"→ 特征声明错，**数据问题** |
| L4/F19_H02_to_H01 tool_reference | 未声明 tool_access | 数据缺（已知 27 组）|
| L5/F19_H02_to_H01 | engagement 3.9 < 4.0（真）；head_seat_flatness 9.75 最差孔 H01-F12 是底孔（假）；head_seat 4/8 孔落在包围盒外（坐标错）| 混合：咬入不足是真的（要改件），头判据一半是 F-L5-1 |
| L5/F24_L07_to_L05 | stack 31.491 / engagement −19.491 来自 L05-F12 底孔 | **判据问题**（F-L5-1）；6/6 孔 flatness 2.2 是较差端（F-L5-2）|
| L5/T01 seat_flatness | 两端 [0.0, 9.9]，叠厚 5.8..15.7 | 头侧平、远端台阶 → **判据问题**（F-L5-2）|
| L5/F01_hipyaw_back | engagement range null（S288 塑料自攻无数据）；head_seat T01-F04 39/72 悬空 | 前者数据缺（诚实）；后者要看 T01-F04 头侧是否真悬空，可能是较差端 |
| L6/left_knee | 48 条碰撞全在切刀区间外、策略包络内，峰值 619 mm³ @+90° | 工作空间问题（已知，控制端限位）；按 F-L6-3 不该落件级 BLOCK |
| L7/L01 | load_criteria null；load_path_local_section 自检恒红 | 数据缺 + 判据自述"量的不是路径截面"，诚实红 |
| L5/fits.pla.bearing_outer_seat_6704 | nominal 27.15 ∉ [26.95,27.05]；无关系实测；assumed | 真冲突（+0.15 间隙 vs 过盈目标）——**数据/设计问题**，红得对 |
| L3/KO07 | tube × N02 7.445 mm³ | 真交集（KO07 224.3→224.26 与刻面共同作用，build #7 预期变小）|

### 2.6 "换件不重写"守住了没（方向 6）

- 守住的：L1（无件号/坐标，只有二分/采样参数）、L2（除镜像轴 `[1,-1,1]`）、L4/tool_access（除 mirror_y 约定与 `_MOVER_RULE` 文案）、L5（除 `fits.pla.m2_*` 桶路径）。
- 没守住的：**L3**（KO 编号分派、`"B01"` 豁免、zone 数字、`neck_pitch/head_yaw`、KO15 `+x`、`servo__/bearing/orig_` 前缀）与 **L7**（元件按 category 认领、镜像对数 5、`"TPU"` 子串、筋 ±0.1）——加一个摄像头或换一颗舵机，这两层必须改代码。L6 的 `_CUTTER_LABELS` 标签表写死但层已自报。L0 写死发布目录路径与量级阈值。
- 不在 data 里的判据数字：l0:63/126（3/300、50/400）、slice_l1.py:165（0.75）、l7:1664/1690（±0.1）、l5:162（关联半径 0.6，是关联容差可接受）、l2:`_STEP_OFFSET=0.3`（探针位置，与 M2 孔径的比例是隐含前提）。

### 2.7 性能与可维护性（方向 7）

- 全跑 1795 s（09-12 首跑）；本次实测反例包 ≈ 430 s（L0 全程 7:14，L0 本身几秒）；L2 单层 ≈ 800 s（1239.7 − 430）。build ≈ 8 min（交接 §2）→ 元规则 10 的目标 ≤ 4 min，实际 7.5×。
- 无跨轮内容 hash 缓存：格子里已经带 `inputs_hash`，但没有"hash 没变就不重算"的路径；L2 `_GEOM_CACHE`（l2:78）、L4 `_Geo`、L6 `_Scene` 都是进程内按路径缓存。
- 单件不能独立跑（F-核-6）；`--out` 换目录后没有 prev 则 242 格 obligation_unmet，无法单层判读。
- AABB 粗筛：L3 双层、L4 `_proven_clear_*`、L6 `evaluate` 都有；L2 `faces_near_axis` 外接球预筛有，但 `hole_wall_min/occupancy/region_scan` 全网格。
- 建议顺序：① 反例结果缓存（省 7 min/轮）；② 格级结果缓存 keyed by `inputs_hash`（同时修好 `--parts`）；③ L2 的 `_min_wall` 二分（≤13 次全层 buffer）与 `_merge_coaxial` O(n²) 是下一个热点。

---

## 3. 总评

**这个 Gate 现在给出的"绿"能不能信**：分三档。L0 的网格/发布/冻结 sha256、L3 的件×件与轴承整环、L6 的单轴扫描、L5 的坐面（在头侧确实平的件上）——这些绿有真证据，能信。L4 的 step 绿、L3 的元件×载体绿、L7 的整机重心/扭矩绿——是条件绿或同源自证，只在 yaml 诚实/建模一致的前提下成立，Gate 自己证明不了。`L2/_coverage 171/171`、`L1/_calibration`、`L5/*/fit_measured_geometry` 这三处是结构性空绿，读它们等于没读。再往底层看，反例包只验 state 不验 severity，已经让两条判据无声降级；所以"每个绿都被反例证明过会红"这个前提本身不成立。

**红里有多大比例是判据问题而不是件的问题**：915 条红判据里 401 条（44%）没有实测数——370 条数据缺（tool_access 27 组、线束 9 束、关系无 contact 段、公差表 null）、31 条判据未实现——这些是 Gate 的作业，不是件的。514 条有数的里约 204 条（40%）落在我判定判据设计有问题的族：L5 坐面/螺丝头 78（较差端 + 底孔当坐面）、L2 孔周壁 65（错量纲）、L6 全上游行程 41（工作空间）、L1 min_wall 16、L2 直径 4（刻面）。合计 **6 成以上的红不是件的问题**。剩下约 300 条里真要改件的集中在：L6 已知工作空间碰撞（等控制端限位定）、L2 通/盲/存在与声明不符（其中相当部分是 features.yaml 登记错，如 L01-F09）、L3 KO07、L5 咬入不足（F19 3.9、F21 2.7、F26 3.5）、L1 支撑侵入禁撑区的大数值件（H01 2539、N03 188）。

**最该先修的三件事**（都指到代码）：
1. **反例包的断言层**：`negatives/_harness.py:134-150` 加 `assert_red(check, severity, require_measured)`，`runner.py:37-58` 校验 `expect` 结构；补 L0（单位错米）、L3（轴承只查截面）、L7（舵机质量×10、电池挪 200 mm、forcerange 0.7）、L6（区间反转）反例。没有这一步，其它所有修复都无法证明自己修对了。
2. **三处空绿 + 两处错红，一次改完**：`l2_features.py:1250` covered 移到发 finding 之后并给 sweep/corridor 类加 else→unknown；`calibrate_l1.py:62` 把 `PASS & evidence_n==0` 计 unknown、`l1_printable.py:549-566` 对 n_eval=0 的 BLOCK 判据发 unknown；`l5_function.py:814` 只在 relation_contact PASS 时登记；`l5_screwhead.py:292` 跳过 pilot_hole、`l5_function.py:488-513` 与 `l2_features.py:342` 坐面只判头侧（头侧从 tool_access.outward 取）；`l2_features.py:1338` diameter 用棱边而不是内接中位数。这一批改完，记分卡红数预计下降 ~90 条，且都是"判据错"不是"件好了"。
3. **让"旧绿失效"变成机制**：`core.py:248-253` implicit 加 `duckstructure/*.py`，各层 inputs 补 placed/（L7 尤其）；新增 `gate.py --verify`；`l6_motion.py:444/514/1148`、`l7_mass.py:816/893` 的硬编码 STALE 改成 unknown(WARN) 或新状态；`core.py:329-330` 覆盖率义务在无 id 时写红格并给 assembly.yaml 补 id。然后 L4 再补 `present ⊇ 推导集合` 这条判据，L4 的绿才不再是条件绿。

附：本次审计没有改动仓库任何被跟踪文件；`--layers 0` 的记分卡在 scratchpad 里（`gate_out/scorecard.{json,md}`），只用于观察，不是放行依据。

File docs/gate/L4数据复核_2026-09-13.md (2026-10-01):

# L4 数据复核 —— assembly.yaml 19 步 / 36 动作 / 24 工位（2026-09-13，审计第二批 D14/D15）

> 复核工具：`tools/gate/layers/l4_assembly.py` 新增的 `present_covers_derived` / `present_only_installed`（审计 F-L4-1 的落地，
> 反例 `negatives/n_l4_present_derived.py`），以及 `tool_access.run_tool_access` 对改动后工位的复算（scratch 脚本，不入库）。
> 数据改动全部在 `tools/gate/data/assembly.yaml`，逐条见 `data/CHANGELOG.md` 2026-09-13 第二批节。

## 1. 结构性发现：`step` 编号不是物理顺序

09-12 主线程写的 motions/tool_states 已经按物理顺序声明在场集合（步 6 横滚舵机装入时 T01/偏航舵机/L01 都在），但 `already_installed`
仍按 `step` 编号累加，两者自相矛盾。本次：

- 每步加 `seq`（物理顺序）与 `subassembly_of`；顶层 `subassemblies` 声明子总成闭包（只声明一次）。物理顺序：
  1,2,3,4,5（踝）→ 7（大腿舵机）→ 9（偏航舵机进 T01）→ 10（6702 + L01 上躯干，F02 从空杯腔拧）→ 6（横滚舵机进 L01，F03）→ 8（腿）
  → 11,12,13（头台面）→ 18（头壳合上）→ 14（头贴颈俯仰舵机）→ 15（颈上躯干）→ 16 → 17 → 19。
- `already_installed` 按 seq 重算（文本级替换，其余字段未动）。
- 步 8 / 14 / 15 一步跨两张台面，`subassembly_of` 在 motions 里逐动作覆盖（8a 膝轴承=upper_leg、8b 踝子总成上膝=leg、8c/8d=trunk、8e=body；14b=neck_head；15b=robot）。

## 2. 36 条 motion 与 24 个 tool_states 的 present 复核结果

判据 `present ⊇ movers ∪ {早于本位置进入装配、所属子总成 ∈ closure 的实体}`（按左/右/中央侧过滤）：
**改动后 36/36 动作、24/24 工位全部通过**（改动前也全部通过 —— 主线程写的 present 没有漏障碍；漏的是顺序与工位，见 §3）。

反向判据 `present_only_installed`（present 里出现按 seq 还没装的实体，WARN）剩 5 条，都是**声明粒度**问题，不改数据：
- 步 6 右 / `tool:hiproll_back_R`：present 含左腿全部（作者假设"左腿已完整"再装右横滚舵机）。step 粒度是左右同步，表达不了"左腿先装完"。多算障碍只会更严，留 WARN 记录。
- 步 17 `shell_L/shell_R` / `tool:shells_on`：present 含 `orig_face_part`、`orig_jaw`，但 **assembly.yaml 没有任何一步装这两个原版件**（脸板与下颚）。这是装配序的缺口，不是壳的问题 —— 要补一步（装在哪、什么方向、什么工位）才能扫掠，本次不编。
- 同一步里左侧动作的 present 含右侧稍后才装的件（步 9/10/7）—— 记入 detail 不判（"另一颗已装也通过"是故意多算）。

方向（`outward_world`）没有人工重推：它由 `motion:*` 扫掠与 `step_direction_declared` 用几何判，方向写反会直接红。

## 3. 三组转红的结论（D15）

| 组 | 探针/复算证据 | 结论 | 处置 |
|---|---|---|---|
| **F22 H01→H03**（4 颗 M2×8，从 +z 经 Ø4.65 通道） | 4/4 头的轴向射线只被 `orig_top_head_shell` 挡（22.2 / 32.6 / 31.2 / 39.3 mm）；把顶壳从工位拿掉：刀路 0 mm³、4/4 可见 | **工位写错**：物理上应 H03 合上 → 拧 F22 → 再盖顶壳 | `tool_states.head_shells_on` 去掉 `orig_top_head_shell`，`after_motion: H03_bottom_shell`（步 18 两条动作之间） |
| **F06 髋俯仰法兰**（12 颗 M2×12，头朝 −y/+y 即朝躯干） | 在 `L_hip_on_trunk` 工位 12/12 头被 `servo__yaw2roll_hip_l`（7.15 mm 处）+ 横滚 6704 挡，323 mm³；在腿台面（无躯干）0 mm³、12/12 可见。F04 带着整条腿再拧：3.3e-6 mm³、12/12 可见 | **工位与装配序写错**：L02 必须先在腿台面贴上俯仰法兰拧 F06，再连腿一起套上横滚法兰拧 F04 | 步 8 动作重排：8b' 新增 `L/R_hip_onto_pitch_flange`（movers=L02，台面=upper_leg_bench，沿俯仰轴抽出）；`L/R_hip_onto_roll_flange` movers 改 L02+整条腿、len 60→100（60 mm 内小腿与躯干 ⊥ 投影仍重叠证不出脱离，100 mm 全程 0 mm³）；删 `*_upper_sub_onto_hip`；工位 `hippitch_flange_*` 改台面、`hiproll_flange_*` present 加腿。步 8 十条动作扫掠全绿（本机复算） |
| **F03 髋横滚背**（4 颗 M2×6，头朝世界 −x） | 外排（y=±25.5）畅通；内排（y=±9.5）从坐面沿 −x 13.86 mm 处撞 `trunk`（电池仓前壁，厚 3.5 mm，Ø4 批杆交集 44 mm³）；任意 ±1.9 mm 径向偏移都撞 | **真拧不到（直杆）**：F02 要求横滚舵机未装（从空杯腔向上拧），F03 又要求 L01 已上躯干 → 内排两颗在当前几何上没有直杆刀路 | 不改数据、不改件。三条路给用户：① T01 电池仓前壁在 (x≈−21, y=±9.5, z=110) 开两个 Ø4.6 起子通道；② 声明一支杆长 ≤13 mm 的短柄 PH0（`available_shaft_len_mm`）并让 L4 按它判；③ 改装配序让 F02 能带着横滚舵机拧（现几何不成立） |

## 4. 仍未闭合
- `orig_face_part` / `orig_jaw` 没有装配步（§2）。
- 步 19 电子件（SBC/IMU/buck/switch）无 CAD 实体，`names.resolve` 认不出，L4 只能记 WARN。
- 步 6 左右分步的表达（左腿先完整）需要 step 粒度拆到侧，本次不改。

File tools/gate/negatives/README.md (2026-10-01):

# `tools/gate/negatives/` —— 反例回归包

元规则 8：**Gate 每次运行先跑这里，证明自己每个都能报红，否则 Gate 本身判失败。**
每条是项目真踩过的坑。坏样本一律用"对正常输入做一个最小突变"的方式生成：几何在内存里现造（trimesh 布尔出小网格 →
写进 `tools/gate/out/_neg_tmp/`，不进 git），判据一律取真实的 `data/*.yaml`，只把 parts / features / fasteners /
relations 换成这一条反例自己的最小清单。每个反例 < 5 s（L7 整机量允许 30 s）。

跑法：`./.venv/bin/python tools/gate/negatives/n_xxx.py`（单个）；`runner.py` 跑全包（≈7 min）。

## 结果契约（2026-09-13 起，`runner.check_contract` 校验；缺一项 = 失败）

以前只验 `state`：`min_wall_geometric` / `support_reachable` 降成 WARN 之后反例照过，"翻回 BLOCK 也没人抓"
真发生过（审计 F-反-1）。现在每个 `n_*.py` 的 `run()` 必须返回：

```
{"name", "passed", "expect", "got", "detail",
 "expect_severity": "BLOCK" | "WARN",      # 坏样本应该红在哪一级 —— 必须是层里**现在真实的**严重级
 "red": [record, ...]}                     # 坏样本上真正红了的判据，由 _harness.assert_red 给出
```

- `red` 非空；每条 `state == FAIL`、`severity == expect_severity`、`measured` 非 None（= 抓到缺陷，不是"算不出来"）。
- 专门验"坏声明必须 unknown"的反例（孔阵位置不全、NaN 镜像、区间反写…）另给
  `allow_unknown_red: "<为什么 measured 为空是设计>"`。
- 内核级反例（不经过层）用 `assertions: [{"claim", "ok"}, ...]` 代替 `red`，全 ok 才过。
  **注意 runner 先看 assertions：给了 assertions 就不再校验 red**，所以带已知缺口记录的文件
  （如 `n_l0_units_meters.py` 的 Y-up）把 `assert_red` 的结果也写成一条 assertion。
- 空壳（`passed=True` 但既无 red 也无 assertions）算失败。
- 对照样本用 `_harness.assert_green`（PASS 且 evidence_n > 0，ABSENT 不算绿）—— 判据不能写成恒红。
- 红必须来自层的 `run(ctx)`（或 run 直接调用的层入口，如 `run_declared_motions` / `run_tool_access`）
  发出的 finding，不是只测辅助函数 —— 函数改名/不再被 run 调用时反例要跟着红。
- 严重级只记录不改：层是 WARN 就写 WARN 并在 NAME/EXPECT 里标 `[WARN]`（目前：`min_wall_geometric`、
  `support_reachable`）。

`_harness.py` 提供：`FakeCtx`（含 `mjcf()`）、`base_data`、`box/cyl/export_stl`、`findings`、
`assert_red / assert_green / record / result`。

## 事故表（README 元规则 8 举的例子）

| # | 坏样本 | 怎么造 | 该报红的层 | 报红判据 | 文件名 |
|---|---|---|---|---|---|
| N1 | **空刀**（孔没切出来） | 声明 Ø2.2 通孔，成品上刀没落在实体上 | **2 特征存在** | `<孔>:present` FAIL(BLOCK)，measured "0/1 处到位"，证据数 = 射线数 > 0；对照有孔 PASS | `n_l3_bearing_section.py`（N1 段，走 `l2_features.run`）；孔中段缩径另见 `n_l2_fg07_bore_midspan_necking.py` |
| N2 | **轴承只查截面** | 把 6704 实体换成 Ø27×0.1 的薄片（只有中截面），座外侧留 0.2 mm 唇 | **3 静态装配** | 完整实体 × 座 → `bearing_6704zz:part_vs_component_solid` FAIL(BLOCK) ≈16.8 mm³ 且 `L01:component_bearing_6704zz` 红；薄片按 envelope 20×27×4 反算体积/包围盒**认领不到** → `world_placement` unknown（不许绿） | `n_l3_bearing_section.py` |
| N3 | **压板 0.30 均匀间隙夹不住** | H02 垫柱端面从 −14.85 退到 −15.15，清单仍写 contact=0 / status=ok / src=measured | **5 功能达成** | `relation_contact` FAIL(BLOCK)，有符号配合量 −0.30；贴合对照 PASS | `n_l5_fg13_pad_contact_label_only.py` |
| N4 | **扫掠区间取反** | frozen.yaml 某关节 `range_deg` 写成 `[92, -62]`（头尾对调）；`check_angles(lo>hi)` 只给两端点 | **6 运动** | 期望 `_joints`/该关节 有一条 FAIL(BLOCK)。**现状：层按上游 MJCF 区间扫，frozen 反写只进已退役的 `range_matches_upstream` → 没有任何 FAIL，本反例当前失败，等层在 lo>hi 时判 unknown** | `n_l6_reversed_range.py`（当前 ❌，待层修复） |
| N5 | **螺丝加长 2 mm** | fasteners.yaml F03 M2×6 改成 M2×8 | **5 功能达成** | `screw_length_rule`：总长 ≤ 叠厚 + 盲深 − 0.3，逐孔算 | 无（相近：`n_l5_fg14_shallowest_engagement.py` 验逐孔最浅咬入不按组取 max） |
| N6 | **删一个件** | 从导出集合里拿掉一个件 | **0 网格与坐标** + **4 装得进去** | L0 `stl_exists` 点名缺件；L4 引用该件的步无法构造 | 无（相近：`n_placed_instances.py` 只覆盖 L4 的 `_framework:placed_instances` 实例缺失/重复/跨件占用） |
| N7 | **单位错成米** | 导出 STL 整体缩放 0.001 | **0 网格与坐标** | `units_and_scale` FAIL(BLOCK)，measured 0.04 mm ∉ [3, 300] | `n_l0_units_meters.py` |
| N8 | **Y-up** | 导出前绕 X 转 −90° | **0 网格与坐标** | 舵盘轴心 vs MJCF ±0.05 / 基准轴夹角 ≤0.5°。**现状：`datum_vs_mjcf` 未实现、恒 unknown，包围盒判据抓不到朝向** —— 记录为已知缺口（assertions 里 ok=True 但写明），不假装红 | `n_l0_units_meters.py`（已知抓不到） |
| N9 | **镜像件只改左边** | 右件槽挪 1 mm（包围盒与圆孔中心都不变） | **2 特征存在** | `mirror:surface` FAIL(BLOCK) 1.0 > 0.05；真镜像 PASS；单向 NaN/Inf/空采样必须 unknown | `n_l2_fg09_mirror_rib_only.py`、`n_l2_nonfinite_mirror.py` |
| N10 | **舵盘时钟错 60°** | 把 `horn_holes` 旋转 60° | **5 功能达成（当前不可实现）** | ⚠️ 六孔等分阵列绕自身轴转 60° 是**几何自同构**，任何基于孔阵的判据都抓不到。要真正可检测必须引入非对称基准或用 S288 输出轴编码器零位在装配时标定。`features.yaml` 8 条 `horn_hole` 的 `clock_phase.declared` 恒为 null 且判 BLOCK 是**正确的**（未知=失败）。对应实机项 `bench.yaml:BN13` 第 2 条 | 无（不可几何判定） |

## 现有反例一览（按层）

| 层 | 文件 | 红在 |
|---|---|---|
| 内核 | `n_core_evidence` / `n_core_obligations` / `n_core_severity` / `n_core_retired` / `n_core_coverage_no_id` / `n_core_partial_inherit` / `n_core_verify` / `n_core_waiver` / `n_core_waiver_cell_only` / `n_core_neg_cache_key` / `n_core_keepout_layer_routing` / `n_l6l7_retired_not_stale` / `n_core_layer_error`（gate_guard 09-25：假层模块走真 gate.main —— 层抛 TypeError / 层进程被 SIGKILL / 返回不可解析 → `L<n>/_layer_error` BLOCK + 终端摘要与 md 顶部 ⚠ + 退出码 1；全量空跑加格、子集空跑只提示；干净 → CLEAR 无格） | assertions（build_scorecard / apply_waivers / verify / 反例缓存 key 静态全盖 + 运行时清单 / 禁入体义务按 checked_in_layer 派层 + covered_by_subjects 汇总格 / gate.main 层崩溃·空跑守门） |
| L0 | `n_l0_units_meters` | `units_and_scale` BLOCK；Y-up 已知缺口 |
| L1 | `n_l1_thin_wall` `[WARN]` / `n_l1_overhang` `[WARN]` / `n_l1_support_in_bore` / `n_l1_support_in_box_zone` / `n_l1_support_landing_tiers` `[WARN]` / `n_l1_single_bead_gcode` / `n_l1_missing_array_member`（unknown） / `n_l1_calibration_record` / `n_l1_feature_zone_snap`（hr41g：卡扣/舌片按 id 纳入 `no_support_zones.feature_zones`，面邻域外扩；未纳入/margin 缺或 0/tier 坏/无盒/无此特征 → unknown） | `min_wall_geometric` WARN / `support_reachable` WARN / `support_in_no_support_zone` BLOCK（真 G-code 落点，forbid 级） / `support_in_removable_zone` WARN（removable 级 + 后处理文本） / `min_wall_sliced` BLOCK |
| L2 | `n_l2_fg07_bore_midspan_necking` / `n_l2_fg08_plate_hollowed` / `n_l2_fg09_mirror_rib_only` / `n_l2_nonfinite_mirror`（unknown） | `bore_gauge` / `solid_retention`+`min_section` / `mirror:surface` |
| L3 | `n_l3_bearing_section` / `n_l3_ko01_independent` / `n_l3_ko01_neighbor_zone`（09-21：W 只查载体的两侧边界） / `n_l3_component_envelope` / `n_l3_frozen_items` / `n_l3_keepout_data_driven` / `n_l3_ko22_sweep`（hr41g：bounds_world_mm 包络沿方向后抽；障碍含元件；终点脱离；字段缺 unknown） | `part_vs_component_solid` + `component_<id>`；薄片 → `world_placement` unknown / `keepout_KO01`（声明加深通窗里的料，CAD 切刀看不见；pocket 模式侧出线槽里的料红、window 模式不查）+ dims 缺 → unknown / `part_vs_component_envelope` + `component_envelope_<id>`（占位体挖缺口 → 同源判据 0 绿、独立实体红）+ `envelope_solid_declared` unknown / `frozen_battery_bay_26:BAT_Y`·`frozen_h01_sbc_posts:hole_pitch`·`frozen_imu_pose_vs_cad` BLOCK + `measured_on` 缺 → unknown / `camera_fov_unobstructed`（光轴来自数据，缺 → unknown）·`keepout_intersection`（KO12 豁免只认 exempt[]）·`axis_joint_declared` unknown |
| L4 | `n_l4_split_direction` / `n_l4_zero_length_path` / `n_l4_segment_end_inside` / `n_l4_rigid_subassembly` / `n_l4_tool_far_seal` / `n_l4_tool_seat_origin` / `n_placed_instances` / `n_l4_present_derived` / `n_l4_elastic_declared_warn` `[WARN]` / `n_l4_elastic_outside_zone` / `n_l4_elastic_over_cap` / `n_l4_elastic_missing_decl`（hr41g：声明式弹性接触，共用 `_l4_elastic_scene.py`） / `n_l4_tool_cone_seat`（hr41 落盘 2026-09-25 Lane C：沉头锥面坐面 seats[].cone —— 锥口被料挡 / 锥口外有盖必红、好锥口绿、不写 cone 按平面判必红、cone 缺 src unknown；同轴异位两孔按声明孔深区分，挪 ≤ 孔深或不写孔深仍 unknown） | `step_sweep` / `disassembly_prereq` / `motion:*` / `tool_path_to_outside` / `tool_origin_on_seat` / `_framework:placed_instances` / `present_covers_derived` BLOCK + `present_only_installed` WARN + 缺子总成 unknown |
| L5 | `n_l5_fg13_pad_contact_label_only` / `n_l5_fg14_shallowest_engagement` / `n_l5_fg15_ninth_hole_sloped_seat`（+E 料里 unknown） / `n_l5_self_tap_radial` / `n_l5_fit_measured_only_on_pass` / `n_l5_head_on_pilot_hole` / `n_l5_seat_origin_cutter_mid` / `n_l5_seat_instance_key` / `n_l5_threshold_src` `[WARN]` / `n_l5_pilot_depth_priority` / `n_l5_joins_format`（gate_guard 第 6 项 09-25：joins 被 YAML 拆碎 → 只红该组 `joins_format` BLOCK、该组盲深不从文字取、层不崩、不出 `L5/_layer_error`） | `relation_contact` / `engagement_per_hole` / `self_tap_radial_overlap` / `fit_measured_geometry` / `head_seat_flatness`（坐面起点 = seats[].point_export_local，刀心只当轴锚）/ `head_side` unknown（同 instance 反向）/ `threshold_assumed` WARN + 无 src → `fit_value` unknown / `screw_length_rule`（pilot_depth_mm 优先，不一致 unknown）/ `joins_format` BLOCK(measured=`joins[3]=int 23`) |
| L6 | `n_l6_scene_inventory` / `n_l6_reversed_range`（unknown） / `n_l6_combo_pocket` / `n_l6_target_range_severity` `[WARN]` / `n_l6_target_range_declared`（unknown） / `n_l6_gen_range_vs_free` / `n_l6_undeclared_zero_gap` / `n_l6_harness_sweep`（hr44reg） | `_scene:placed_inventory`；`_joints:range_declared_ordered:*` unknown；`pair_combination` BLOCK（5° 网格抓两轴都非零的 5° 口袋，粗网格假绿）；`single_axis_sweep / pair_combination / collision_buckets / motion_collision` 目标区间外 → WARN、区间内 → BLOCK（assertions 双验）；目标区间声明缺/无序/非数/超域/收窄无 date+reason → 同组判据 unknown；`_ranges:collision_free_range` BLOCK（生成 MJCF range ⊄ 无碰撞区间）+ `_ranges:gen_range_covers_target` WARN（⊉ 目标区间）；`_clearance:min_clearance` BLOCK（零位间隙 0.2 没声明 contact 不豁免，真几何 min_gap 0.109）+ `_zero:undeclared_zero_gap_pair` WARN；`<线路>:harness_sweep` BLOCK（线束模型区内线∩件 / 零位弯 R < 限；调不通 / 替身场景 NOT_RUN(BLOCK)） |
| L7 | `n_l7_mass_torque` / `n_l7_inertia_tensor_all` / `n_l7_static_torque_home_and_range`（含 unknown） / `n_l7_mass_gap_unknown`（unknown） / `n_l7_component_claim` / `n_l7_torque_source` / `n_l7_generalized`（共用夹具 `_l7_fixture.py`：真数据下质量清单有缺口、整机判据一律 unknown，对照用"只删不编"补成完整清单） | `joint:*:static_torque` / `_stability:com_in_support_home` / `joint:*:forcerange_vs_servo_rating` / `_mjcf:inertia_tensor_parsed` / `joint:*:static_torque_home` BLOCK + 区间反写 → `static_torque` unknown / 清单缺一个质量 → `com_in_support_home`·`static_torque`·`head_mass_budget` unknown / `<元件>:component_qty` BLOCK(measured=实例数) + 无 claim → `component_body` unknown / `_load:torque_source_consistent` BLOCK(measured=差值) / `_mjcf:mirror_body_pairs` BLOCK(== 声明对数) + `_load:home_pose_declared`·`_stability:support_polygon`·`rib_thickness` unknown + `threshold_assumed:*` WARN |

补充要求：
- 每个坏样本除了"红"，还要断言**红在对的格子上**（`<件号>.<层>.<检查名>`），红错地方视同没抓到。
- 每条反例都要有"正常样本必须绿"的对照，防止判据写得过严把好件也判红。
- 新踩的坑一律先在这里加一条，再去修 Gate —— 顺序反了就没人知道 Gate 到底能不能抓。
- L6/L7 这类整机层跑不动最小解析件时，允许用替身 placed/（同名 1 mm 立方）或真 placed/ 只读 + 猴子补丁
  层的 `PLACED` / `_SIM_MJCF` / `_Scene`，但断言必须落在 run 发出的 finding 上，并在文件头写明停在哪一步。
- L1 支撑落点（2026-09-13 C-1，取代同日早先的 F-L1-3 过渡保护 + 两遍切片桩）：`support_in_no_support_zone` 按
  `slice_run.parts.<件>.support_landing`（真 G-code 采样点）判，没有记录 / source_sha256 或 zones_sha256 对不上一律 unknown。
  反例件没有真切片，用 `_harness.landing_stub(data, pid, stl, [支撑线段…])`：把"切片器在 export_local 这里放了支撑挤出线"
  写成合成 G-code（`;TYPE:Support material` + G1 E 段），按 slice_l1.main 同一变换转到打印坐标，再交给
  `slice_l1.support_landing` 真实解析 / 采样 / 逆变换 / 对 `l1_printable.no_support_zone_set(data)` 数点。桩只提供
  "支撑在哪"这一事实，不证明切片器会那么放；分级（forbid/removable）、阈值、sha 核对全在层里被检验。
  对照样本也要带桩（没支撑线的空记录），否则主判据是 unknown 不是绿（`n_l1_missing_array_member` 的好样本就是这样）。
  `mutate_zone_data=` 允许建桩**之后**改禁撑区声明，验"声明变了没重切 → unknown"（`n_l1_support_landing_tiers` B）。
- L6 反例共用 `_l6_scene.py` —— 替身 placed/ + 真运动树，`scene_class(keep=, hit_fn=)` 只留几只实体 / 用合成 evaluate 验网格与分档逻辑，`restrict_joints` 只扫几条关节，`gen_mjcf_with_ranges` 造临时"生成的 MJCF"，`run_l6` 猴子补丁 `PLACED/_Scene/_GEN_MJCF/_RANGES_OUT` 跑完还原，真 `out/mjcf_ranges.json` 不被反例覆盖。验真几何间隙的（`n_l6_undeclared_zero_gap`）不给 hit_fn，走真布尔。
- L7 整机层的对照样本必须先过 `_l7_fixture.complete_inventory`（2026-09-13 F-L7-4 起真数据的 static_torque / com_in_support_home / head_mass_budget 因质量清单缺口一律 unknown）；夹具只删不编（无实体无质量的元件 qty=0、无质量的轴承与 orig_* 连实体一起从替身 placed/ 拿掉、6704/6700 收成单一宿主件），是夹具不是对真数据的主张。
- L3 反例（2026-09-13）：KO01 用真运动学 `duckstructure.lib.sfw` 定舵机落位、件是造的；冻结项反例用造的仓/门/立柱/IMU 块 + 最小 frozen 字典（`measured_on` 指到反例件），阈值取真 `tolerances.yaml:frozen_dimension_mm`。
- 2026-09-26（hr46 E 段）退役 `n_l6_harness_sweep`：用户原话『注释掉吧，我已经开始打印了，后面我会再找你，有问题那个时候再修吧。』—— L6 E′ 线束实体模型扫掠调用已注释（l6_motion.py 文件头「E′ 停用」），本反例整文件注释并改名 `retired_n_l6_harness_sweep.py`（运行器只 glob `n_*.py`，不留恒绿反例）；恢复方法写在两个文件头。

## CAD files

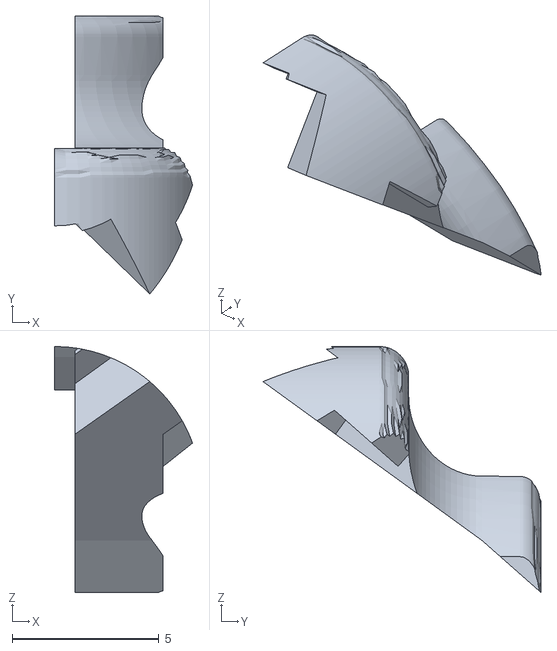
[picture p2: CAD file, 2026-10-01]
duckstructure/data/regions_2026-09-17/hip_R__pair_hip_l_2_x_leg_2.stl
4.70 x 9.46 x 8.37

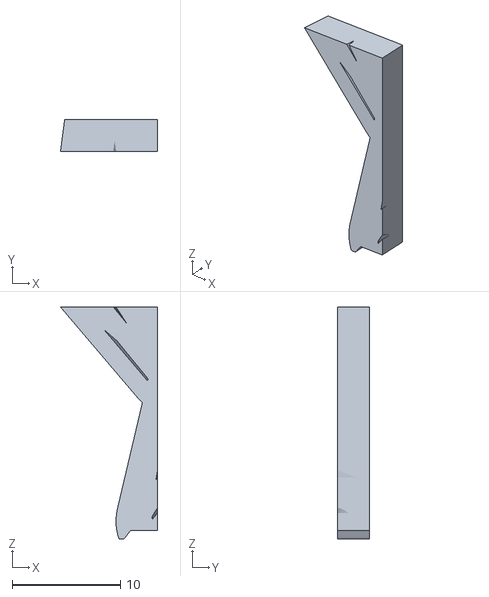
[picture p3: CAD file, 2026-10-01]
duckstructure/data/regions_2026-09-17/trunk__pair_jaw_soft_x_trunk_base.stl
8.97 x 3.00 x 21.4

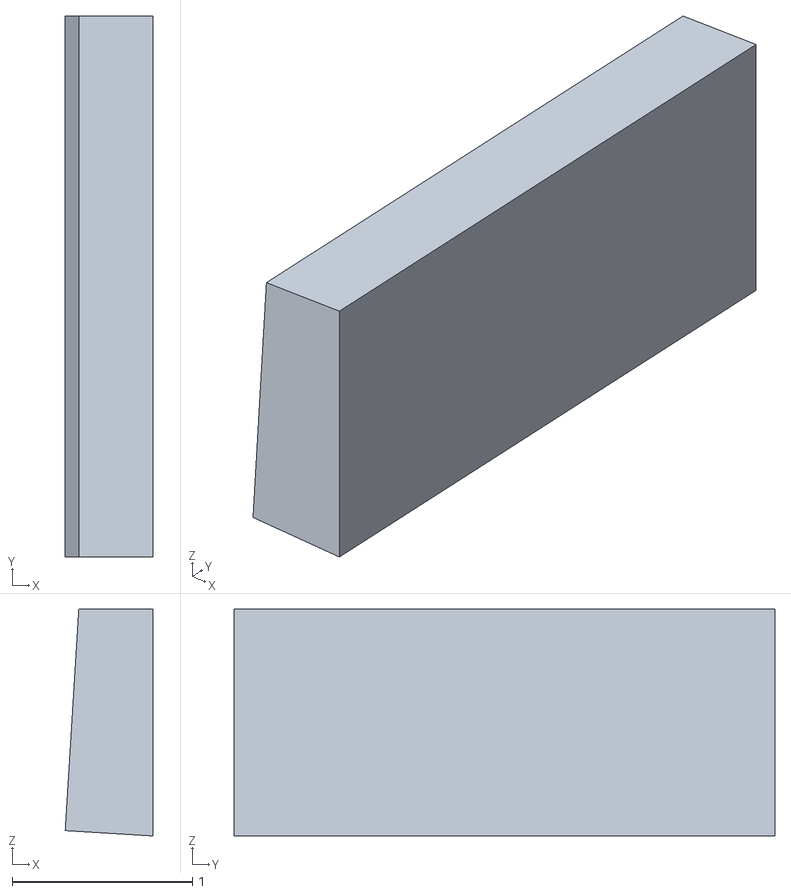
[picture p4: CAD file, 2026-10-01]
duckstructure/data/regions_2026-09-17/servo__trunk_base_bearing_roll__pair_neck_x_trunk_base.stl
0.486 x 3.00 x 1.26

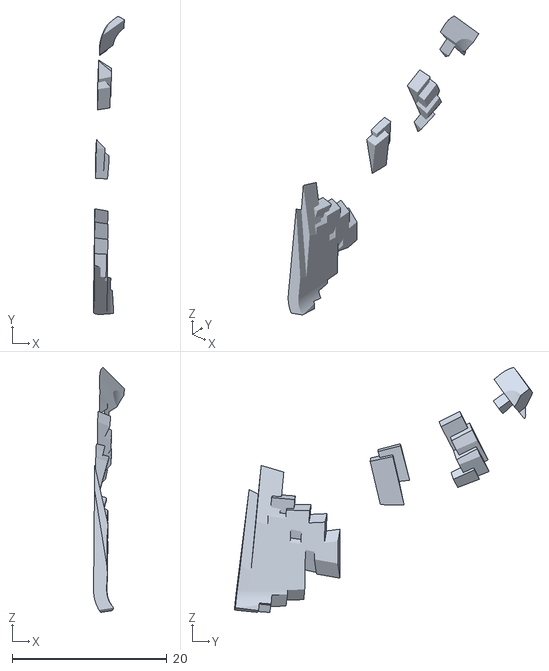
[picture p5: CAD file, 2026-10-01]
duckstructure/data/regions_2026-09-17/orig_jaw__pair_jaw_soft_x_trunk_base.stl
4.00 x 38.6 x 31.7

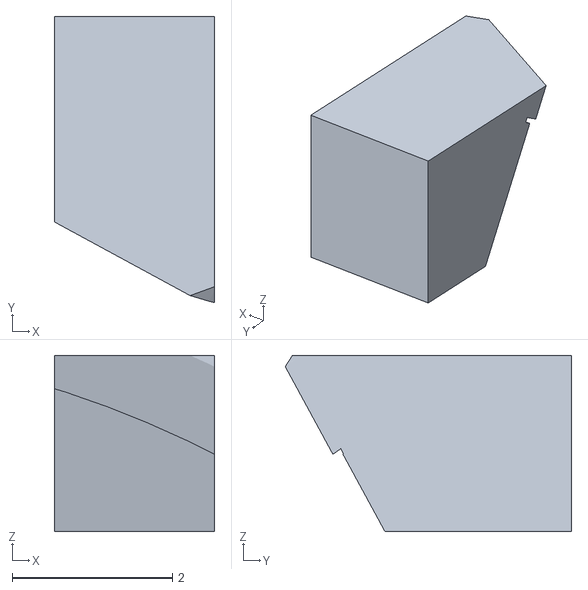
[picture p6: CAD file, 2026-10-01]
duckstructure/data/regions_2026-09-17/trunk__pair_trunk_base_x_upper_leg_left.stl
2.00 x 3.58 x 2.20

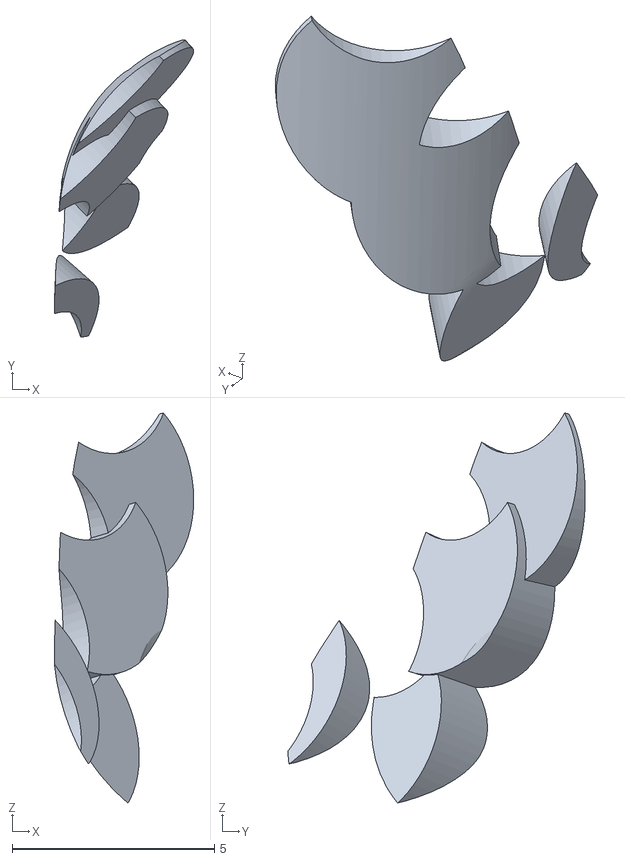
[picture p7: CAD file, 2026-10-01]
duckstructure/data/regions_2026-09-17/orig_jaw__pair_hip_l_2_x_jaw_soft.stl
3.45 x 7.35 x 9.64

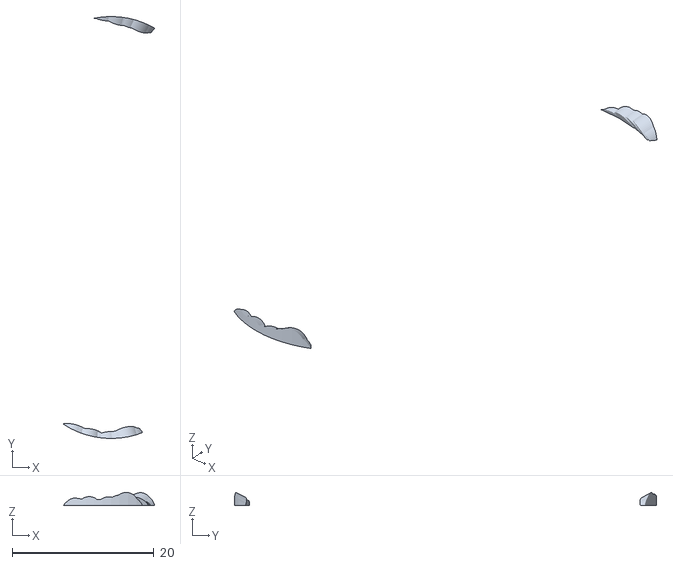
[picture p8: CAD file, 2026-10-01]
duckstructure/data/regions_2026-09-17/trunk__pair_F06_heads_x_trunk_base.stl
12.9 x 59.6 x 1.86

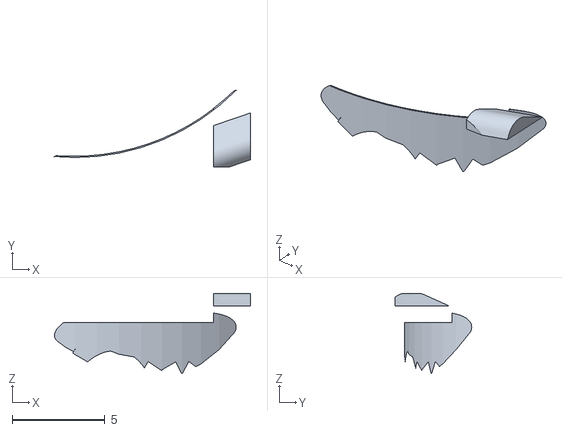
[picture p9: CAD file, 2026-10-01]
duckstructure/data/regions_2026-09-17/trunk__pair_hip_l_2_x_trunk_base.stl
10.6 x 4.14 x 4.34

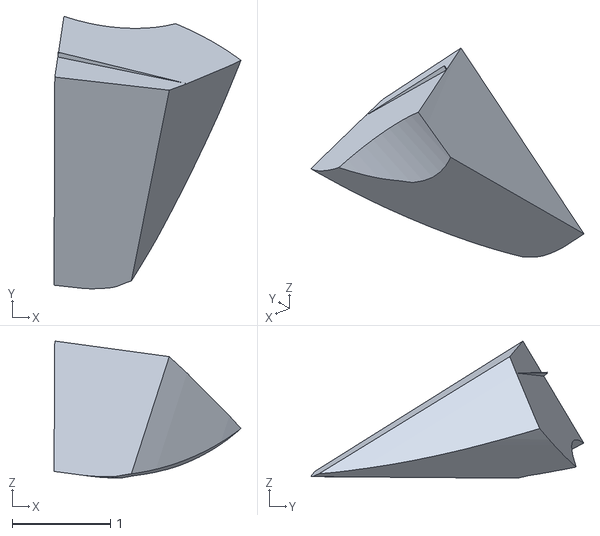
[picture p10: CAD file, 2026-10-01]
duckstructure/data/regions_2026-09-17/orig_top_head_shell__pair_jaw_soft_x_leg_2.stl
1.90 x 2.77 x 1.39

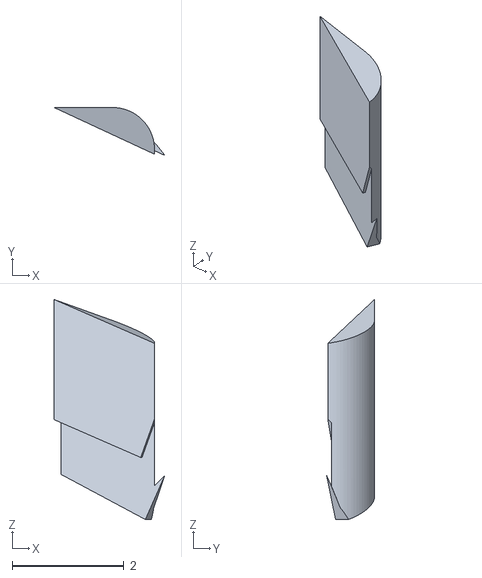
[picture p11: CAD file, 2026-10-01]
duckstructure/data/regions_2026-09-17/hip__pair_hip_l_x_trunk_base.stl
1.98 x 0.859 x 3.94

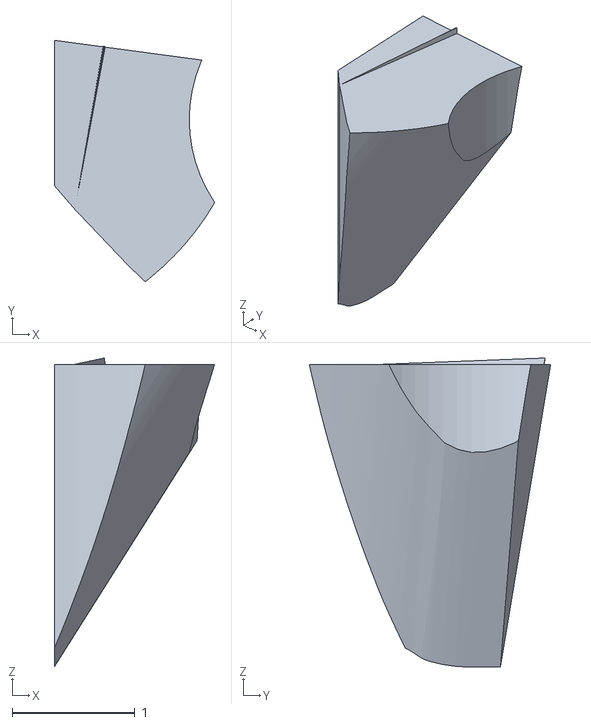
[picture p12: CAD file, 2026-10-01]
duckstructure/data/regions_2026-09-17/lower_leg_R__pair_jaw_soft_x_leg_2.stl
1.31 x 1.97 x 2.52

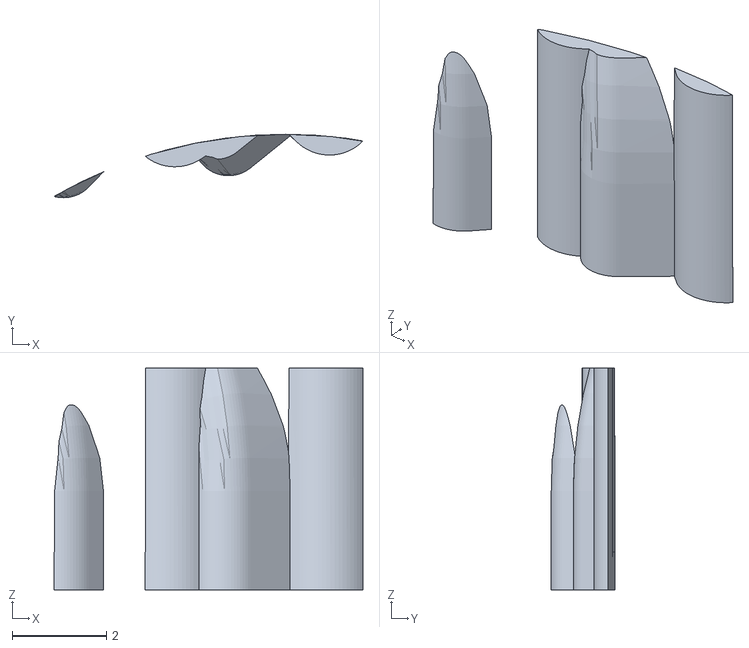
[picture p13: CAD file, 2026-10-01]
duckstructure/data/regions_2026-09-17/ankle_rear_arm_R__pair_ankle_right_x_hip_l_2.stl
6.55 x 1.35 x 4.70

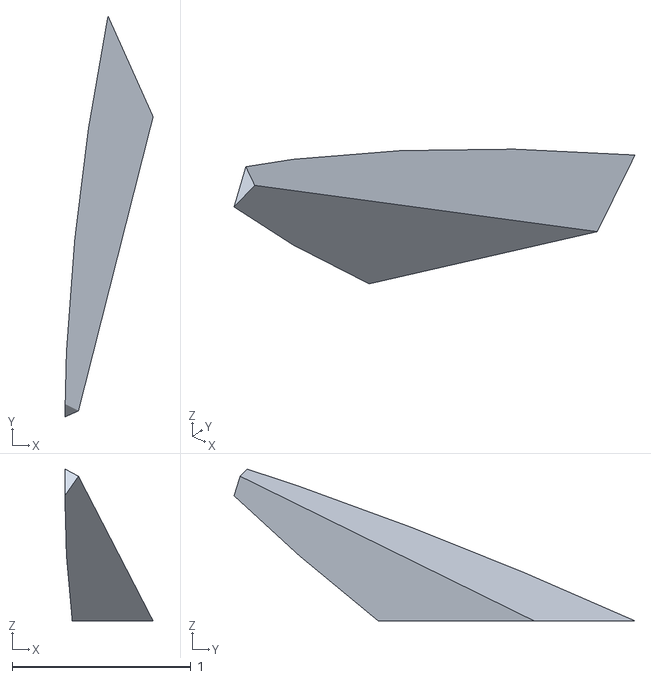
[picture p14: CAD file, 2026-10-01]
duckstructure/data/regions_2026-09-17/upper_leg__pair_servo_trunk_base_yaw2roll_x_upper_leg_left.stl
0.494 x 2.24 x 0.849

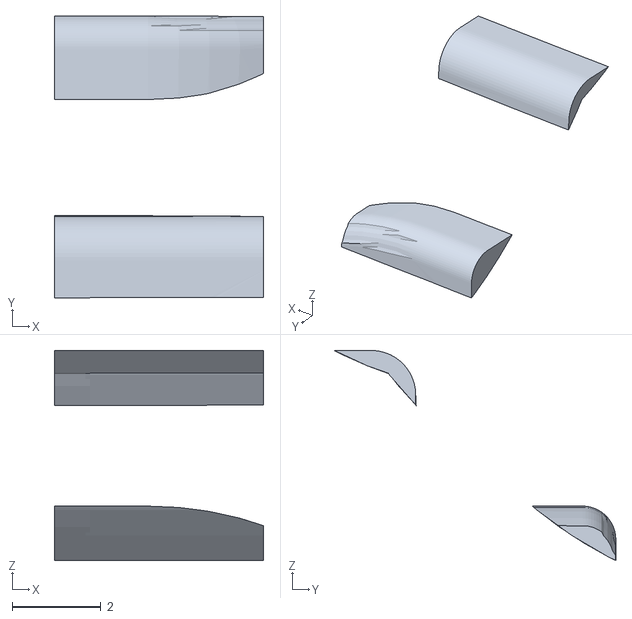
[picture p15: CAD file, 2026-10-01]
duckstructure/data/regions_2026-09-17/hip_R__pair_ankle_right_x_hip_l_2.stl
4.70 x 6.33 x 4.72

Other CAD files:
duckstructure/data/regions_2026-09-17/neck__pair_neck_x_trunk_base.stl
duckstructure/data/regions_2026-09-17/neck__pair_jaw_soft_x_neck.stl
duckstructure/data/regions_2026-09-17/hip_R__pair_hip_l_x_hip_l_2.stl
duckstructure/data/regions_2026-09-17/trunk__pair_hip_l_x_trunk_base.stl
duckstructure/data/regions_2026-09-17/head_bottom_shell__pair_jaw_soft_x_neck.stl
duckstructure/data/regions_2026-09-17/hip_R__pair_hip_l_2_x_jaw_soft.stl
duckstructure/data/regions_2026-09-17/hip_R__pair_hip_l_2_x_trunk_base.stl
duckstructure/data/regions_2026-09-17/hip__pair_hip_l_x_hip_l_2.stl
duckstructure/data/regions_2026-09-17/lower_leg_R__pair_hip_l_2_x_leg_2.stl
duckstructure/data/regions_2026-09-17/orig_jaw__pair_jaw_soft_x_neck.stl
duckstructure/data/regions_2026-09-17/trunk__pair_trunk_base_x_upper_leg_right.stl

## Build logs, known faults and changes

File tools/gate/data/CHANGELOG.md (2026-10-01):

## 2026-09-25 hr43e —— hr43d 全链暴露的 6 项修正 + 协调员 20:10 收尾四件；报告 docs/design_2026-09-17_bearing_rebuild/hr43_work/hr43e_修正报告.md
几何（build_fast #1 --only H03,H08,H09；#2 --only H03,H09）：静态 0 / mechanical PASS（未闭环仅 B01）/ 扫掠 243 → 238（head_pitch 少 −90° amp_bracket × shell_L）；旧检查域内 0。
- **L6 目标区间内清零**：H09 竖板 y 29.5 → 32.4 起、脚板 y 32.4..37.2 / x −24.8 起、F38 孔与 H03 凸台 y 33 → 34.7（头俯仰 × 颈俯仰只绕 y 转，shell_L 头系 y ≤ 31.76）→ H09 区间内 33 → 0；H08 +y 下纵梁 +x 端 81.8 → 75.5、托面前下角 x ≥ 76 / |y| ≥ 12.5 挖到 262.8（新 H08-F07）→ H08 区间内 3 → 0；两格 BLOCK → WARN。H09 刻字改竖排（stamps.py）。
- **收尾（协调员 20:10）**：① H03 凸台顶 224.5 → 225.0、H09 脚板 / 竖板底抬 0.5、F38 底孔 4.3 → 4.8（尖余 0.8）；② F36 M2×5 → M2×6（用户有 M2 自攻 PA ×6）咬 3.4 → 4.4，H09 两立柱背面加 Ø4 × 1.0 背凸台（新 H09-F05），Ø1.7 通孔 5.0；③ H08 扎带头放托板 +y 侧上方 / 竖板一侧、不放前下角（只登记）。
数据：fasteners（F36 / F38 joins 加引号 —— L5 整层崩溃根因；起子 PH1 杆长 75 定义一次（锚 &avail_shaft_ph1_75）、PH0 38 组别名引用 → tool_reach_declared 20/20 PASS；F36 / F38 规格 / 底孔 / 坐面）、components（tape_foam_1mm 撤成 bus_adapter note、counts 28 → 27；amp / mic / sbc envelope_solid → none + 多盒记录 —— 单盒按 OBB 中心落位压进件是登记口径，真元件 × 件 = 0）、features（+H08-F07 +H09-F05，329）、parts、assembly（步 18 文字）；negatives/_l7_fixture 删 tape_foam_1mm（n_l7_* 7/7）。assembly.yaml:3160 / parts.yaml:1183 两处同类未加引号流式项一并加引号。
**没跑全链**；L6 real_pose_collisions 过期待重采。

## 2026-09-25 hr43d 全链实跑（chain_d，18:02–18:35，无缓存）；汇总 docs/design_2026-09-17_bearing_rebuild/hr43_work/chain_d/汇总.md
Gate BLOCKED ✅147 ❌426 ⬜6 🪦1，反例 82/82；真实姿态 119/5601（= hr43c，新增 ankle_foot_R / ankle_rear_arm_R × zz_adapter 两对，alpha_stand）；build 扫掠 243。**L5 功能层整层崩溃**（fasteners F36 joins 首项未加引号被 YAML 拆成 4 项，第 2 项 float → l5_function TypeError）→ ❌ 476 → 426 大头是这一层缺席、不是转绿；hr43e 修。其余层正常；新件 H08 / H09 L6 目标区间内 3 / 33 条（BLOCK）、L3 功放 / 麦克风 / Radxa 包络压进、L7 tape_foam_1mm claim none、L4 F38 缺 available_shaft_len_mm —— 均交 hr43e。

## 2026-09-25 hr43d —— 转接板平放螺丝托板 H08（B′）+ 功放挪后脑 H09（E′）+ 删无用件 + 电子件加固；报告 docs/design_2026-09-17_bearing_rebuild/hr43_work/hr43d_改件报告.md
几何（build_fast --only H01,H03,H05,H08,H09 #1；#2/#3 --only H08,H09 重生成 zz_*）：静态 0 / mechanical PASS（未闭环仅 B01）/ 扫掠 243 = 216 + 27（全是 head_pitch −65..−90° 的 zz_amp / H09 × 躯干，同姿态 H03/H05 已交躯干；旧检查域内 0）。
- **新件**：H08 转接板托板（竖板照 H07 贴 H01 三根旧立柱 F35 复用 + 托面 2.0 厚 z 262..264 + 0.5 胶坑 36×26 + 2 扎带位 + 两条下纵梁；板脚印 x 51.8..81.8 = 研究位 +x 5.8 让 F22#3 起子通道 KO09）；H09 功放支架（竖板 + 两 Ø4 立柱 F36 + 脚板 F38 2×M2×6 拧 H03 新凸台 F24/F25）。H07 退役。
- **electronics**：功放 AMP_S_C/R → 后脑 +y (−10.8, 28.8, 235.8)、板竖放元件面 +x（孔改局部系开）；转接板平放占位 ADP_FLAT / adapter_boxes；排针直插杜邦功放 5 腿出壳即弯改朝 −x（40 号斜 45°，逐针天花板余量 ≥1.39）。
- **head / head_top**：H03 删 F14 槽 / F22 平床 / F23 胶坑 / F15 USB 插头井 / USB 壁切口，加 F24/F25；麦克风台 / UBEC 托条下沉 0.8 放 1 mm 泡棉；H05 删 F06 压筋 / F09 叉齿，喇叭肩面抬 0.5 放泡棉环。
- **wiring_head**：ADP 平放口位（L 边 −x，A 边 +y：PH 57.8 / XT30ext 71.7；B 边 −y：Type-C 59.9 / XT30in 74.4）；19 根线重走（功放 5、喇叭、USB、12 V、UBEC 进 + 出 2、S1 两腿、麦克风 6；S1 转接块与嘴 PH 短线留 hr43c 原位）；CSI 板上方段抬 0.35、折 1/2 挪 x 64.5。check43d_final：线∩件（非预期）≤0.087、三关节 + 嘴扫 0；弯折低于声明 12 根（端头拐角，声明值 assumed）。
- **注册**（简报文件清单外，新件必需）：build_fast.py / build.py 加 H08 / H09、去 H07；stamps.py 加 H08 / H09 件号。
数据（定点文本改，旧值 *_was_until_2026_09_25_hr43d；注释行数不变）：components（bus_adapter fixation zip_tie by [H08]、cable_dupont_ff captive by [H05]、tape_foam_1mm claim none + mass 0.3 assumed —— 修 hr43c 全链三条登记红；amp / speaker / mic / UBEC / XT30 加固登记）、features（−14 +14）、parts（36）、fasteners（F35/F36 改接 H08/H09，新 F38）、assembly（步 18 P″、各组在场件）、harness（HB01/03/04/06/08/10/11 hr43d_route）、printability（H08/H09）、keepouts KO14、frozen 注。
**没跑全链**；快车道 hr43d_head 见报告。

## 2026-09-25 hr43c —— 后脑零鼓包 + 排针直插杜邦四件 + 复审 #2 B1/B2 + M4 登记；报告 docs/design_2026-09-17_bearing_rebuild/hr43_work/hr43c_改件报告.md
几何（build_fast --only H01,H03,H05,H07 #1/#2：静态 0 / mechanical PASS（未闭环仅 B01）/ 扫掠 216 = 215 + head_pitch −90° zz_sbc × zz_xt30 0.315（目标 −50° 之外；dy +1.0 把 USB-C2 口壳推进平衡头 y 带 0.17））：
- **electronics**：板 SBC_A_C (−3,−2,257) → (−3.5,−1.0,256.5)（协调员四档 dy 比选，逐针最差 @Rc2.0 +1.127/+1.129/+1.041/+0.821 → +1.0）；孔 / 顶面包络随板；板角 R3 → 2.45（官方 DXF）；zz_adapter40 退役 → 新占位 zz_gpio_dupont（R2 针位 14 个杜邦壳 2.54×2.8×14 十字 + 17 段出壳即弯管，UBEC 4/34 用 OD1.6、Rc 2.0/4.0）；功放 AMP_S_C y 0 → −2.0（B1）。
- **head_top（H05）**：F10 鼓包退役（外形 = 放大原版）；新 F15 = 排针上方横筋局部削 + ±y 两端内皮减薄 ≤0.55（壁 ≥1.227）；吊柱随板（柱长 8.0/16.9/9.86/18.17）、(8,±) 贴杜邦壳削平离 1.0；F14 板角让位删（板↔原壳 1.284）。
- **head**：H07 托面 / 立柱 / 纵梁随功放 −y 2.0 + F22 右前脚 Ø5.3 缺口过孔 + web（F22 4/4 起子路径通）；H01 删空着的 (−29,239.5) 立柱；H03 转接板 +x 壁 + 立柱 → 竖粘平床 F22 + 0.5 胶坑 F23（协调员 14:55，15:20 起位置待用户重定）。
- **wiring_head**：dupont OD 1.3 → 1.4；PINMAP R2（6→14、39→20、1→17 一分二）；20 根线 Radxa 端改壳顶接续点重走（_HR43C_ROUTES）；CSI 候选路径 csi43c_a..d（3 折，对件 / 线 0 交，HB06 → 候选）；USB 弯头随板。
数据（全部定点文本改，旧值留 *_was_until_2026_09_25_hr43c；注释行数都不变）：features（−H05-F10/F14，+H05-F15、H07-F06（half_only）、H03-F22/F23；改 H05-F11/12/13、H07-F02/03/04、H03-F14、H01-F03/04；322 → 324）、parts（H01/H03/H05/H07 体积 / feature_count、motion_instances zz_gpio_dupont）、components（gpio_rightangle_40p qty 0；cable_dupont_ff 认领 zz_gpio_dupont + 实量 + 一分二 3；+tape_foam_1mm；27 → 28）、harness（HB04/05/08/10/11 hr43c 线、HB06 候选、HB01 usb）、assembly（head_shells_on 按 P′：−zz_sbc +amp_tray/zz_amp；zz_adapter40 → zz_gpio_dupont；步 18 plugging_steps_hr43c）、fasteners（F35 按 Lane C 口径；F36/F37 随件 + schema 缺口记名）、frozen（H01 立柱删一根例外）、keepouts（KO14 注）、printability（H03/H05/H07 注；快车道 merge 刷了切片记录）、manifest（zz_gpio_dupont）、head_specs（head.py 指纹）。
**没跑全链**；快车道 hr43c_head L1/L2 与 hr43b 同红（H07 首次进快车道，L2 0 BLOCK）。

## 2026-09-25 hr43 —— Radxa 搬后脑（方案 A，用户 09-24 17:25 定）+ 直排针功放托板 H07 + 顶壳鼓包/吊柱 + H03 6700 下半环恢复；报告 docs/design_2026-09-17_bearing_rebuild/hr43_改件报告.md
几何（build_fast --only H01,H03,H05,H07 #1–#4；#4 终版：静态 0 / mechanical PASS（未闭环仅 B01 基线）/ 扫掠 215 = 基线 210 + 6 − 1，增减全在 head_pitch −87.5..−90°（目标 −50° 之外、旧检查域内 0）/ H07 单实体）：
- **electronics**：sbc_boxes → 方案 A 平放 (−3,−2,257)，板 z 256.2..257.8、四孔 (−14.5/8.5, −31/27)、DXF 禁布 r3；新占位 zz_adapter40（盒 A x −2..26 × y −28..24 顶 279.8，板边外那截 z ≥ 266.5；盒 B x 26..44 × z 266.5..274.5，assumed，N03 横滚扫掠 + 喇叭后挡夹出来的带）；amp_boxes → 直排针版 (56,0,263)。旧函数 *_was_until_2026_09_25_hr43。
- **head_top（H05）**：F10 后脑鼓包（盒 A 上内面 ≥ 280.85，最高抬 8.26 @ (−2.5,−29)，壁 2.0，内面后坡/外面前坡 ≤45°）；F11 四吊柱 Ø6 泪滴（柱端 Ø5.4、长 8.58/20.06/10.48/20.03）+ 长柱筋（+x 片 45° 下沿延到内面）；F12 Ø1.7 底孔；F13 SoC 出风槽 5×1.6；F14 Radxa 板角让位（壳↔板 0.734 → 1.04）；功放卡座 F04 拆除（旧 build 留痕）。
- **head**：新 H07 build_amp_tray（竖板贴 H01 旧四柱端面 x 66，3×M2×8；托面 + Ø4 立柱托功放 2×M2×5）；H03 刀序修复 → 6700 下半环恢复（截面 46/46）。build / build_fast / stamps 注册 H07。
- **wiring_head**：_HR43_ROUTES 20 根重走（15 杜邦 17 腿 + 喇叭 + 嘴扁线 + USB-C 15 cm）；线∩件最大 0.087（基线）/ 新增 0.020；CSI 200 未建（HB06 未闭合，待用户答）。
数据（全部定点文本改，旧值留 *_was_until_2026_09_25_hr43）：parts（H07 新件、counts 35；H01/H03/H05 role/houses/体积）、features（−H05-F04，+H05-F10..F14、H07-F01..F05、H07-S01；311 → 321；H03-F17 注）、fasteners（F25 停用 qty 0；+F35/F36/F37；screws 176 → 181）、components（sbc/amp fixation、camera_csi 200、+gpio_rightangle_40p；26 → 27）、harness（HB01/04/05/06/08/10/11）、assembly（步 18 装序 P′ + plugging_steps_hr43 + motion a/d + 3 个 tool_states）、printability（H07；H05 注）、frozen（h01_sbc_posts 例外 H01_posts_no_longer_carry_Radxa_hr43）。tools/sim/cad_geometry_manifest.json body_for_part + amp_tray / zz_adapter40（hr38_refresh_manifest --apply，build #4 后）；head_specs.json head.py 指纹刷新。
**没跑全链**（build / slice_l1 / audit_motion / policy_pose_collisions / gate 都没跑）；features counts 321 不含 Lane C 并发加的 E01-F01/F02、E03-F01（列表 324 条）。

## 2026-09-25 hr41 遗留落盘（主设计 Lane C）—— hr41g 待补 yaml + Gate 判据三处缺口；报告 docs/design_2026-09-17_bearing_rebuild/hr41_遗留落盘_2026-09-25.md
数据（全部定点文本改，旧值留 *_was_until_2026_09_25）：
- **features**：B03-F04 `elastic_contact`（PETG，过盈 0.25 assumed）；B03-F05 第二实例 `box_export_local` = nominal_box_mm；J02-F04 / J03-F03 `geom.hex_prism`（六角穴对边 4.2 + 平边外法线，nominal 不改）；新增 E01-F01（window Ø24.4）/ E01-F02（boss Ø32）/ E03-F01（boss Ø3.4）。311 → 314。
- **printability**：`no_support_zones.feature_zones` 登 B03-F03/F04/F05/F06（removable，face_margin 0.45 assumed，主设计定档）→ B03 zones_sha256 变，待全链 slice_l1 重切。
- **assembly**：步 21 battery_lid 与拆序 seq0 末段加 −x 20。
- **keepouts**：KO22 `sweep_direction_world` [-1,0,0] / `sweep_len_mm` 60，status → checked；counts 补 checked_offline。
- **fasteners**：F34 声明 6 个锥面坐面（seats[].cone，工位 motion:18:f_J01_up），feature_hole_map 孔锚改 J01 export_local。F27 重复键 hr41 已清（yaml.compose 全库 0 组）。
判据（tools/gate）：tool_access 锥面坐面 + 同轴异位孔按孔深区分（n_l4_tool_cone_seat）；L2 六角穴对边/对角量法（n_l2_hex_nut_cavity）；L3 fixation 采样 seed=0；反例夹具 _harness.base_data 只留本反例特征的 feature_zones、n_l3_ko22_sweep c_real 取"去掉两项的真 KO22"。

## 2026-09-24 hr41 —— 头部阶段二（复审 #1 B1 + M1–M7 + 摄像头贴板 + MINOR；Radxa 搬后脑相关项转 hr42）
几何（build_fast --only，#1–#5，每次静态 0 / 张嘴 0..30° 0 / mechanical PASS / 扫掠 210 对同 hr39f 基线）：
- **J01 v2**：两臂带内内面 52.05、外侧加厚 1.0，毂补平 Ø20，两毂各 3 个 M2 沉头孔，r 7.1 @ 350/130/250°（不对称防错）。法兰 6 孔、沉窝、垫台、轴颈都取消。
- **新件**：J02 +y 法兰转接盘（3×M2×5 上法兰，装一次不拆，压 3 颗螺母）；J03 −y 轴颈盘（进 6700 内圈，压 3 颗螺母）；H06 摄像头压框。
- **H05**：两侧开 21 宽嘴毂槽；加 2 个保持凸台（x 64、y ±48.5）；F06 压筋改叉形，增加 −x 齿。
- **H03**：转接板 +x 立柱 ×2；保持螺丝过孔 + 锪平 Ø4.6 到 z 232.30；UBEC +y 窗改 U 槽，扎带改沿 x 绕。OTG 地板口做了又撤（Radxa 在 hr42 搬走）。
- **H04**：摄像头贴板（去立柱，Ø23 通窗，0.8 浅坑，四角定位销，压框凸台 ×2），麦克风槽改下开口，取消 E01 销孔。
- **眼睛**：E02 改 Ø24 圆筒；E03 凸 0.2；E01 去销。
- **zz_camera**：前移 5.9，PCB 补 4×Ø2 孔。
- **head_specs**：N08 耳按 120° / −60° 登记；起子障碍改为步 11b 工位。

数据：
- **frozen**：head_pitch 目标 [−50, 90]；h01_sbc_posts.exceptions 2 条（m6）。
- **tolerances**：新桶 machine_screw_hex_nut（null / unknown）。
- **features**：293 → 311。
- **parts**：34 件。
- **printability**：新增 J02 / J03 / H06。
- **fasteners**：
  - F27 改为 H06 2×M2×8，工位 h04_bench。
  - F28 改为 J02 3×M2×5，工位 j02_bench。
  - 新增 F33_H05_keep（2×M2×8，工位 h05_keep_screws）。
  - 新增 F34_jaw_hub_to_adapters（6×M2×5 沉头机牙 + 6 螺母；锥面坐面 L4 不支持，tool_access 不声明）。
  - F30 注。
  - counts 173 → 176 + 6 螺母；「全自攻」claim 加 correction。
- **assembly**：
  - 步 18 = 装序 P 7 个 motion + 插线步 M6。
  - 步 19 起补 J02 / J03 / H06。
  - head_shells_on 改为 c 步。
  - 新工位 j02_bench / h05_keep_screws。
  - 步 11 F30 注；拆序注；m8。
- **components**：
  - camera / mic / UBEC / 转接板的 fixation 按 hr41 重写，附六向自核 fix41.json。
  - sbc 写「固定方式待 hr42：H05 四柱」。
  - 6700ZZ by J03-F01。
  - mic insert_dir 补上。
- **harness**：
  - HB06 顶层登规格 150 / 11.3 / 16×5，status「走线待 hr42 按后脑位置重走」（m7）。
  - HB01 USB 改 15 cm（m12）。
  - HB03 xt30 4.83/6.0、HB04 ubec_in 2.62/4.0，登「下限 assumed、待实测」。

自核（非 Gate）：
- 装序 P a–g 带线 / 不带线全 0；张嘴 −5..30° 全 0。
- 反例：旧 H05 × J02 1.819、旧 J01 × H03 783。
- 坐面 F28 / F27 / F33 全过；线束 check41_final 与基线同。
- 头部审计 PASS 100 / NOT_RUN 3 / FAIL 1（N07 老问题）。

**Gate / 全量链 / audit_motion / 真实姿态都没跑**（协调员 16:05 禁令）。报告：docs/design_2026-09-17_bearing_rebuild/hr41_头部阶段二.md。

## 2026-09-23 hr39c 4c —— 按 4a 终版 build（21:51）补齐 4b 留下的 4a 遗留 TODO（yaml 28 处 + 报告 5 处）、刷新体积、重跑 feat_calc
几何不改。**features**：H04-F01 / F02 / F04、E01-F01、E02-F01 注明摄像头倒装绕光轴转、光轴不动、几何不变（todo → todo_resolved_2026-09-23_hr39c_4c）；H03-F14 加 `usb_wall_cuts_2026-09-23_hr39c`（−x 壁 y −13.6..−4.4 开口、y −24..−13.6 削到 z 239）；H03-F15 改 ⑧ 出线方向（+x → 缝里竖起）；H01-F03 加 `otg_relief_2026-09-23_hr39c`；H03-F13 加 `ubec_two_end_leads_2026-09-23_hr39c`（托条 + 墙底开口）；frames.per_part E01–E03 / H05 / J01 注改为 4a 复量相同，H01 / H03 / H04 的 export_stl_bbox_mm 换成 hr39c 实量（旧值留在 `_was_until_2026-09-23_hr39c`）。**parts**：H01 19.083 → 19.080、H03 40.631 → 40.622，其余 6 件复量相同；todo → changes_4a / todo_resolved；E01 / E02 notes；`jaw_soft_mass_2026-09-23_hr39c.refreshed_2026-09-23_hr39c_4c`（make_mjcf 口径 283.48 g，贴近实物仍 242.2 g）。**harness**：HB06 route / route_len 96.0 / 线长实测 142 / 触点奇偶 / open_items；HB01 usb_link 状态、净空、**purchase_spec（假设，下单核对）**。**components**：TF 卡对 ⑧ 的影响与换卡步骤、bus_adapter 注、camera_csi 加 `mount_2026-09-23_hr39c`（倒装）、buck_12v_5v 加 `placed_note_2026-09-23_hr39c_4a`（两头出线）。feat_calc 用 `hr39c_work/data4b/run_feat_calc_4c.py` 重跑（旧值读 `yaml_before/features.yaml`，避免平移两次；输出 `feat_records_4c.json`）：65/65，25 条记录 + 6 条平移与 yaml 逐项一致。电池 / 开关条目没动（另有评估）；counts 不变（features 279）。

## 2026-09-23 hr39c —— 整头改版数据登记（4b：头等比放大每侧 +10、新嘴轴、转接板挪到 Radxa 前面、圆眼三件；数据轮，几何 = build 第 3 次 19:02）
脚本 `docs/design_2026-09-17_bearing_rebuild/hr39c_work/data4b/feat_calc.py`（常量 → export_local，placed 快照逐条核 pos 有料/无料 65/65）+ `sync_4b.py`（文本级替换，原文件备份 `data4b/yaml_before/`）。**parts** 27 → 30（E01 白外圈 / E02 黑眼珠 / E03 高光）、头部五件 hr39c 块（体积 / 改了什么 / TODO）、J01 role 改新嘴轴、**motion_instances 补 bearing_jaw / servo__jaw_soft_jaw（hr38 漏登，L6 整层塌的根因）+ 圆眼三件、zz_ubec → jaw_soft**、新顶层 `jaw_soft_mass_2026-09-23_hr39c`（make_mjcf 口径 281.4 g / 贴近实物 ≈242 g）；**features** 264 → 279（删 H03-F08 tub；新增 16 条；重写 H01-F17 / H03-F09 / H03-F12 / H04-F03 / H05-F01 / J01-F01..F04；平移 6 条；frames.per_part 加 E01–E03）；**keepouts** KO01 row 15 嘴两口 free / usable 2、row 14 bus_uses both；**harness** HB01 头链 S1 → 14 → 8 → 7 → 6、S6 取消（一分二 5）、新买 PH 双头 10 cm、HB03/04/05/08/10/11 头内线长、HB06 CSI 定金色 22→15 同面线（线长待测）；**components** bearing_6700zz housed_by + H01/H03（hr38 L4 约 15 格 present 缺 bearing_jaw 的根因）、bus_adapter 槽/压筋/装入方向、S6 取消、PH 10 cm 采购、麦/UBEC/喇叭/功放新位；sbc_radxa_zero3w 记 TF 卡永久占位（−y 端，包络 67）与排针侧/背面分项实测（10.3 / 1.4 → 包络 13.3）；**assembly** 步 18 嘴子总成挪到脸板之后 + 新动作 eyes_onto_face_plate、zz_ubec 步 19 → 18、步 13 与三个早期工位去掉误塞的嘴三件、步 20 / 拆序 0 / head_on_headpitch 补全头件；另修 hr38 遗留口径：步 3/4 parts 的 '6700' → bearing_left_ankle / bearing_right_ankle（型号按外径解析会把 bearing_jaw 算进踝子总成 = hr38『约 15 格 present 缺 bearing_jaw』根因）、裸名 top_head_shell → H05 / head_top_shell（拆序 3 movers 补喇叭/功放）；离线用 L4 derive_present 核：全部动作 present ⊇ 推导最小集，缺 0；**fasteners** F30 耳 120°/−60°、F28 新嘴轴孔位；**printability** E01–E03 朝向。**TODO(hr39c-4a)**（4a 在改，主 agent 补）：摄像头朝向/位置（H04-F01/F02/F04、E01–E03）、CSI 线路由（HB06）、USB-C2 → 转接板线（HB01.usb_link）、OTG 让位（H01 立柱）、H03-F14/F15；件体积待 4a 重新 build 后刷新。**未动**：tool:head_shells_on（F22 从上拧要求顶壳不在，与步 18 顺序矛盾，hr37 起就红）、MJCF（全量链重生成，Radxa 重复计算那时修）。验证由全量链给出。

## 2026-09-22 hr37 —— H04 脸板 + 麦克风台 + 电子件占位实体（改件，全链；20:56 起，分数见记录 45）
几何：**H04 脸板**新件（替换原版 face_part：平板层原样保留、填旧孔、13.6 方镜孔、4 根 Ø4.5 立柱 Ø1.7×5 底孔、麦克风边浅槽、刻字内面）；**H03-F12 麦克风台**（2.0 台 + 三面墙 + 唇，Ø4.2 沉坑 + Ø1.5 声孔）；**T02** collar 面板足印以上壳皮削平（`tail.SWITCH_TOPFLAT`）。
placed 新实体：zz_sbc / zz_mic / zz_camera（jaw_soft）、zz_imu / zz_switch / zz_ubec（trunk_base），orig_face_part 不再导出。
数据（`hr37_sync_data.py`）：parts H04 + motion_instances + counts 26/253；features per_part.H04、H04-F01 window / F02 pilot_hole ×4 / F03 slot、H03-F12 boss（by_kind/by_part 同步）；fasteners **F27_camera_to_H04** 4×M2×4 自攻（tool_access 4 坐面 @PCB 背面 x 72.6，工位 h04_bench；杆长 unknown not_measured）；assembly 步 18 加 sbc_onto_posts / face_plate_into_groove 两组 + H03_bottom_shell 带 zz_mic、步 19 元件改 zz_*、步 20 / 拆序 0 / head_on_headpitch 随头 +4、tool_states h04_bench（26）；components 六件 claim + envelope_solid（UBEC = 腔包络 15×4.5×18，WAGO 无实体并注明原因）；printability parts.H04 down [1,0,0]；tools/sim/cad_geometry_manifest.json body_for_part；head_specs head.py 指纹；stamps H04。
待用户定：UBEC 选型（Matek 2 焊点 / 找 ≤15×4.5×18 带线款 / 头里再探）、WAGO 减到 0 改走转接板 XT30 拓展口。

## 2026-09-22 hr36 —— hr35 回归修：发布包 build_fast.py 同步 + F14 叠厚 3.55→3.40（数据轮，件同 hr33；15:21 起 采样 → Gate，分数见记录 44）
**结果 ✅134 ❌382**（历史最好）：恰好 `_release` 源码 21/21 与 F14 crosscheck 0/6 两条转绿，0 新红。文案待下轮：printability H03 note "hr35 抹平"→"接受不改件"、F14 engagement note 方向 +16.4 → +13.0。
fasteners **F14_headpitch_flange** `stack_mm` 3.55→3.40、`engagement_mm` 2.45→2.60：hr35 Gate L5 `stack_from_seat_crosscheck` 逐孔实量 [3.4]×6，记录值是 09-12 惰轮端面 −12.85 时的旧值（F14b 在 hr26 已改 3.40，F14 漏改）。发布包 `06_CAD源码/duckstructure/build_fast.py` 复制为仓库版（hr35 m-01 shell_R 一行修后未同步 → L0 `_release` `source_copy_sha256` 20/21 红）。

## 2026-09-22 hr35 —— F14/F14b 坐面 + 拆序 seq 0 + 注释/口径（数据轮，件同 hr33；14:50 起 采样 → Gate，分数见记录 43）
**结果 ✅133 ❌383**（hr34 ✅133 ❌382）：F14/F14b 起子路径三项 + disasm00 + L5 坐面四项转绿；新红 = tool_reach_declared ×2（实物杆长未知）、counterbore_depth/head_vs_neighbours WARN ×2、F14 stack crosscheck 差 0.15（旧值）、_release 源码 20/21（build_fast.py 未同步）→ hr36。
几何：**不改**。H03 梳齿（hr33 复审 M-01）四种修法都不干净（并集再 minkowski >40 min；grow 0.75 不消反出夹点；闭运算填孔切除体与 hr33 完全相同；口袋区开运算留碎片）→ 根因是壳皮在扫掠包络擦过处的薄鳍，不是刀参数；切片 rc 0 会丢掉，**接受不改件**（复审建议 ②，记录 43）。`head.py` 恢复 hr33 版。
数据：fasteners **F14_headpitch_flange / F14b_headpitch_idler** tool_access 坐面重生成（`hr35_seats_f14.py`：hr31 探针片段，每孔 2 候选取离孔最近 t −15.45 / 3.55；hr33 复审 M-02：壳后拧 F14 的可达性此前未算）；assembly.yaml（`hr35_sync_data.py`）补回 hr34 往返丢的 7 行注释、`head_on_headpitch.present_note` 改"整机 55 件不含髋内轴承/轴套/原版嘴脸"、disassembly_order 新增 seq 0 头子总成 +z 提起（movers = 步 20 的 17 件 + orig_jaw/orig_face_part；counts.disassembly_entries 8）；features H03-F11 `verified_2026-09-22_hr33` 数字口径（±31 起 0.08/0.14、±32 yaw 0 档 0.7/2.3、全档峰 1.9/3.4）；printability parts.H03 `note_2026-09-22_hr33`（8.9 mm²、brim/raft、梳齿）。`build_fast.write_cache` shell_R 修（复审 m-01）。L4 冒烟 vs hr34：F14/F14b 三条路径判据全绿（reach 55.6 峰 0、6/6 可见）、disasm00 0.0、只有 2 条 tool_reach_declared 预期红。

## 2026-09-22 hr34 —— F20 壳螺丝装配顺序：头子总成改在壳之后挂（数据轮，件同 hr33；12:57 起 采样 → Gate）
数据（`hr34_sync_data.py`，PyYAML 往返、文件头注释保留）：assembly.yaml seq 重排 —— 步 14 只留头俯仰舵机进 N01（seq 11，subassembly neck，F13）；步 15 颈上躯干轭只带 N01 + 两颗舵机（seq 12，movers 3 件）；步 16 电池（13）、步 17 壳（14，present 剥掉 19 个头件 → **F20 起子 +z 不再被头壳挡**）；头台架步 11/12/13/18 → seq 15–18（already_installed 补 颈/电池/门/壳）；**新步 20**（seq 19，robot）= 原 14b 头子总成从 +z 落到头俯仰舵机法兰 + F14，workspace body_all、在场 = 整机 55 件；步 19 电子件 → seq 20。tool_states：neck_servo_in_N01 / neck_on_trunk / battery_door_on / shells_on 剥头件，head_on_headpitch → after_step 20、整机在场。subassemblies 注释、counts（steps 20 / verified 11 / declared_motions 19）、disassembly 1/2/6 加 hr34 注释（拆壳前先提头）。L4 冒烟（`gate.py --layers 4` vs hr33 记分卡）：变色 10 条全绿 —— F20 `tool_path_to_outside` FAIL → PASS（reach 51.2、peak 0）、`screw_head_visible` 0/4 → 4/4；step17 `present_only_installed` shell_L/shell_R 与 tool:shells_on 三条旧红转绿（原因同一个：头件在 seq 上还没装却在场）；step20 motion 峰值 1.7e-14、motion_coverage / present_covers_derived / present_only_installed / step_sweep 全绿；0 新红。发布目录 12:55 已同步 hr33 件 + 源码。 **出分 ✅133 ❌382**（hr33 ✅129 ❌385）：预期转绿全部兑现（_release ×2、F20 ×2、step17/shells_on ×3、step20 ×5），0 倒退；step14 的 3 条随动作搬到 step20。

## 2026-09-22 hr33 —— H03 让位刀按策略包络（横滚 ±30）+ grow 0.45（改件；12:1x 起全链，分数见记录 41）
几何：`head.py` 新常量 `HEAD_ROLL_SWEEP = (−30, 30)`（让位刀横滚扫掠范围；`HEAD_ROLL_TARGET` ±25 不改，L6 判 BLOCK/WARN 的边界仍是 frozen 目标区间）、`N02_SWING_GROW` 0.4 → 0.45（消 hr32 的非流形顶点，复审 m-01）。依据：hr32 真实姿态剩 5 个 head_bottom_shell×neck_pitch 碰撞全在 head_roll −26.8..−28.2°（策略实际包络 −28.15..24.04），复审第 3 节第 4 条倾向 (a)。试 build（scratch h03_hr33/test.log）：削 747.5 mm³（hr32 349.8，多 397.7；口袋 6 → 4，合并）；19 个试验姿态全 0（含 hr32 剩的 5 个和 ±30 四角；±32 仍 0.7 / 2.3）；非流形顶点 0；与 H03-F08 转接板口袋交集 0。
数据（`hr33_sync_data.py`）：features `H03-F11` 整块重登（count 4、sweep_range head_roll [−30, 30]、sweep_samples [44, 13]、grow 0.45、4 实例 pos/bbox 全部核过为空 → 都用 bbox_mm、removed 747.38、verified_hr33）；`head_specs.json` head.py 指纹刷到 hr33；`l6_motion.py:79` → `policy_steps_2026-09-22_hr33`。**链模板改序**（`hr33_go.sh`，复审 m-03）：build → slice + merge → 审计 ∥ 扫掠 → 采样 → Gate；build.py 末尾写快车道缓存。预期：L6 head_yaw+head_roll 仍绿、`real_pose_collisions` 里 H03×N02 归零（88 → 83 姿态）、L0 H03 nonmanifold_vertices 绿、L1 H03 first_layer_area 再变（记录）、L2 H03-F11 4 实例绿。F20 装配顺序（拆 seq 16）→ hr34 数据轮。 **出分 ✅129 ❌385**：H03×N02 真实姿态归零（84/39/16）；新判据 nonmanifold_vertices 揭出 H01 ×1 / L05 ×3 旧夹点（WARN，待修）；L1 H03 first_layer 8.9 mm²；发布目录 12:55 同步。

## 2026-09-22 hr32 —— H03 下头壳给 N02 让位（改件：H03-F11）+ hr31 复审数据小修（09:00 起全链，分数见记录 39）
几何：`head.py` 新 `n02_swing_cut`（HEAD_YAW_TARGET (−116.4, 95.4) × HEAD_ROLL_TARGET ±25，5° 网格，N02 minkowski ±0.4，N02 在 H03 系 = A_r(−θr)·A_y(−θy)·N02，逐 θy 并 11 个 θr 副本从 H03 减）；起因：真实姿态 1502/5601 head_bottom_shell×neck_pitch 交叠（走路 1293，峰 55.6 mm³，hr10 起每轮一样）从没进过待修清单（Gate校验_2026-09-22 §一 1）。试 build：削 349.8 mm³（6 块：前下沿 x 39.5..46.5 两块 117/107、后下沿 x −21..10 两块 62/58、|y| 29..35 薄片 3.4/2.5），H03-F08 口袋 / H03-F10 N07 通道 0 交集；16 个试验姿态（目标区间四角/两端/区间外）交集 hr29 9–52 mm³ → 0。
数据（`hr32_sync_data.py`）：features 新 **H03-F11**（sweep_cut，6 实例 pos=块内点 / bbox=块外包盒，export_local）、counts 248→249 / sweep_cut 15→16 / H03 10→11；parts H03 feature_count 11、features_total 249；fasteners **F12b stack 5.55→5.40、engagement 2.45→2.60、孔中点 −15.625→−15.70**（惰轮端面 −13.0，09-14 CHANGELOG 写了没落地，hr31 复审 m-01）；9 组 `stale_since`→`stale_until_2026-09-22`、`tool_access_probe_2026-09-13`→`_was`（m-03）；features T01-F20.geom 重复 depth_kind/through 去一份（m-04）。`l6_motion.py:79` → `policy_steps_2026-09-22_hr32`。
**不改**：F04/F16/F17 stack_mm（复审 M-01：登记值对，L5 只量宿主件一段）；F26（unknown 是设计行为，BLOCK 不可豁免，等非打印件登记方案）；F20 装配顺序、元件占位块 → hr33（先单独看让位对 L6 的影响）。
**hr32 出分（10:10）✅130 ❌384**（= hr31）：转绿 F12b `stack_from_seat_crosscheck`、L6 `head_yaw+head_roll` pair_combination；新红 L0 `_release` ×2（未同步，预期）、L2 `H03-F11:occupancy`（实例 4/5 薄片外包盒中心在料里）。真实姿态 head_bottom_shell×neck_pitch **1502 → 5**（峰 3.14 mm³，5 个都是 head_roll −26.8..−28.2° 超出目标 ±25°）。**链的顺序 bug**：`merge_slice_run` 在采样之后改 `printability.yaml` → 采样指纹作废、`real_pose_collisions` unknown（hr29 同病）。
**hr32b（10:20，件不变）**：features `H03-F11` 实例 4/5 `bbox_mm` → `extent_mm`（不在 L2 BBOX_KEYS，判据点只剩 pos）+ occupancy_note / occupancy_fix 注释；发布目录同步 hr32 24 件 + 源码；`l6_motion.py:79` → `policy_steps_2026-09-22_hr32b`；链改为 采样 → Gate（slice 不重跑，printability 已稳定）。 **出分 ✅131 ❌383**：L0 `_release` ×2 + L2 H03-F11 转绿、0 倒退；`real_pose_collisions` measured 88/5601（hr31 1512；head_bottom_shell×neck_pitch 5 姿态峰 3.14）。 **复审 `hr32_review.md` BLOCKER 0 / MAJOR 2 / MINOR 6 → 收尾**：`head_specs.json` head.py 指纹刷新（M-01）；printability parts.H03 note 贴床 79.2 → 17.3 mm²、切片开 brim（M-02）；features H03-F11 `verified_2026-09-22` 补“让位的 Gate 证据 = L6 pair_combination + real_pose_collisions，L2 只证 6 点无料”（m-04）；`policy_steps_2026-09-22_hr32/run.json` 标注指纹作废（m-05）；`l6_motion.real_pose_collisions` 指纹不一致时点名是哪个依赖文件变了（m-03）；L0 新判据 `nonmanifold_vertices`（m-01，顶点面扇不连通 = 夹点；hr32 H03 有 1 个 @ (41.7, 8.01, 220.59)，hr33 让位刀 grow 0.45 消掉）。

# `tools/gate/data/` CHANGELOG

## 2026-09-22 hr31 —— hr30 复核：F26 的 T01 前壁孔是接收孔（只改数据，几何同 hr29）
数据（`hr31_sync_data.py`）：features T01-F20 kind/check_class screw_hole → **pilot_hole**（+ depth_kind cutter_length / through true / thread_engagement 2.4；by_kind screw_hole 18 / pilot_hole 7）—— 螺纹咬在 3.5 厚前壁里，穿件是非打印的 PCB（叠厚 1.6 记在 F26.stack_mm）；L5『pilot_hole 无头不量』→ 坐面/叠厚/咬入各条转 unknown（PCB 不是打印件，Gate 量不到），不再有 hr30 那两条假红和 seat_* 假绿；fasteners F26 joins 文案、shaft_len_mm / channel_len_mm 115.4（09-09 旧孔位）→ 58.4（hr30 L4 实测 reach 58.316）、seat_measurement_note_hr31、counts 文案 M2×4；tolerances pla_self_tap rule 文案『IMU→T01 前壁 3.5』→ 2.4。真实姿态重采 `policy_steps_2026-09-22_hr31`。Gate hr31 出分（02:55，`gate_full_2026-09-22_hr31.log`）**✅130 ❌384**：对 hr30 FAIL→PASS 12（present 11 格 + L5/F20 engagement_per_hole；F20 tool_origin_on_seat 是新判据 None→PASS 不算转绿）、9 组 tool_reference 红消失（转由坐面判据接手：8 组 tool_origin_on_seat / tool_path_to_outside / screw_head_visible 全绿）；新红 26 条里 9 条 tool_reach_declared（杆长实物未知，预期）、8 条 head_vs_neighbours WARN（判据未实现，预期）；**真发现**：① F20 壳螺丝起子 +z 118 mm 被头壳挡（tool_path_to_outside / screw_head_visible，装配顺序）；② `stack_from_seat_crosscheck` 4 组对不上 —— F04 实测 2.7 vs 记 7.5、F16 2.5 vs 5.25、F17 3.15 vs 5.25、F12b 5.4 vs 记 5.55（**复审 M-01 纠正**：F04/F16/F17 登记值是对的，是多件叠层，L5 只量了宿主件一段 → 不改数，改判据串件量或加归因注释；只有 F12b 是真旧值 5.55 → 5.40）；③ F26 T01-F20 改接收孔后 head_locator 指向的两孔全是接收孔、穿件 PCB 不在 placed/ → head_seat / engagement_per_hole = unknown（记成 FAIL/BLOCK，**就是 part1 预期的**；本段初稿写“转 FAIL 而不是 unknown”是误读，复审 M-02 纠正），hr30 那两条假红、五条假绿都没了。②③ 归 hr32（② 只改 F12b；③ 要么按非打印件完整登记、要么 waivers，zz_imu 占位块解决不了 L5）。复审 `hr31_review.md`：BLOCKER 0 / MAJOR 2 / MINOR 6，hr31 可作 hr32 基线。真实姿态 17/7/7 不变，`real_pose_collisions` 仍 BLOCK 1512 姿态。；**part2（`hr31_sync_data_part2.py`，Gate 校验 §六 B）**：assembly.yaml present 补已装件 —— seq 14 motions H03_bottom_shell / top_head_shell、seq 16 motion neck_servo_into_N01、tool_states H02_on / N02_on_headyaw / head_on_headpitch / head_shells_on / headyaw_servo_in_N03 / neck_servo_in_N01 各加 seq 11 装入的 `bearing_head_yaw` + `bearing_head_roll_A`；tool_states hiproll_flange_L / _R 各加 `hip_pitch_sleeve` / `hip_pitch_sleeve_R`（hr30 L4 `present_covers_derived` 红 11 格；不是采购缺件，是在场清单漏写 → 扫掠少了障碍，可能假绿；预期 11 格转绿、对应 step_sweep / tool_path 可能因障碍变多而新红 = 真结果）；**part3（`hr31_sync_data_part3.py`，Gate 校验 §六 C）**：fasteners.yaml tool_access 坐面重生成 9 组（F02 / F04 / F08 / F10 / F12 / F12b / F16 / F17 / F20）—— 根因：Ø10.5 分度圆定案后法兰孔 r 4.75 → 5.25，09-12/13 探针的坐面没跟着重量 → L4 `tool_reference`（坐面不在孔轴上，1e-6）27 组整体红；probe_seats 对 hr29 件重量，只接受每孔候选面唯一且坐面数 = qty 的组；F06（2 孔无面）/ F14 / F14b（每孔 2 候选）/ 背孔 11 组 / F23 / F25 / F29 / F30（脚本无 SPEC）共 18 组不动、继续红，留 hr32。预期：9 组 tool_reference / tool_origin_on_seat 绿，tool_path_to_outside / screw_head_visible 第一次真跑（可能真红）；tool_reach_declared 仍红（杆长实物未知）；**L4 冒烟（`gate.py --layers 4 --skip-negatives`，scratch）两处补**：① `motion_coverage` 要求 motions[].present 与 required_motion_groups[id].present 逐项相等 → seq 16 neck_servo_into_N01、seq 14 H03_bottom_shell / top_head_shell 的 required_motion_groups.present 同步各加两只头部轴承；② F20_shell_to_T01 feature_hole_map 前两项（T02-F03 / T03-F03）加 `instance: 0`（tool_access.py:75 用它索引 geom.instances 逐孔列表取 axis，先例 F04/F05/F07；两孔 axis 均 z）。冒烟 1：9 组里 8 组 tool_origin_on_seat / tool_path_to_outside / screw_head_visible 全 PASS，只剩 tool_reach_declared（杆长实物未知）；present_covers_derived 11 格全绿

## 2026-09-22 hr30 —— hr29 Gate 两条真红 + 一处漏改（只改数据）+ 用户当日定案（几何同 hr29）
数据（`hr30_sync_data.py` / `_part2.py` / `_part3.py`）：features H01-F17 改 instances 逐实例 bbox（原合并 bbox 中心落在前立板料里 → L2 occupancy 红）；fasteners F26 feature_hole_map 改新孔 (−23.1, ±10.16, −8.35)（hr29 漏改）、补 head_locator_map_indices / tool_access 坐面（T01 前壁外侧面 x −21.1，头朝 +x，工位 tool:imu_install）/ stack 1.6（PCB）/ engagement 2.4，**spec M2×5 → M2×4**（通孔 3.5 墙，screw_length_rule 5 > 1.6+3.5−0.3）；assembly tool_states.imu_install（after_step 9）+ 步 10/19 文案；components camera_csi 定型 Radxa Camera 8M 219（09-22 已下单，envelope datasheet、mass 到货称）、battery 花牌同规格换牌、sbc 已下单、cable_dupont_ff 优信、UBEC 输出改杜邦公对母 40 cm、屏相关/"换香橙派"/USB-C1 供电/IMU SPI 旧文作废标注；harness HB01/HB03/HB04/HB07 尾部/USB-C1/30 cm 舵机延长线/10 cm ×2 旧文改。发布目录同步 hr29 STL + 源码（hr29 L0 source_copy 红）。真实姿态重采 `policy_steps_2026-09-22_hr30`（yaml 进指纹）。Gate hr30 **✅122 ❌392**（hr29 ✅120 ❌393；新绿：L0 `_release` 两条、H01-F17 occupancy、F26 screw_length_rule / head_seat_exists / head_seat_flatness / seat_flatness / seat_stack_spread / counterbore_declared、L4 F26 tool_origin_on_seat / tool_path_to_outside（reach 58.3）/ screw_head_visible、`tool:imu_install` 工位 2 条；新红：F26 `engagement_from_measured_seat` 0.5 / `stack_from_seat_crosscheck` 差 1.9 —— T01-F20 登成 screw_hole 被 L5 当穿件孔量叠厚 3.5，是登记错（→ hr31 改接收孔）；`tool_reach_declared` 缺实物起子杆长（不编，同其余各组）；反例 5 条 L7 旧失败与 hr28b/hr29 同一批，其余 0 变色）。

## 2026-09-21 hr29 —— IMU 定型 Adafruit 4438 LSM6DSOX（STEMMA QT）+ IMU 走线定案 + N07 起子孔 + H01 顶角缺口 + T01 墙-甲板缝加宽（用户确认 7 项）
几何：`trunk.py` T01 前壁 IMU 底孔 2×Ø1.7 → (±10.16, 111.65)（旧 GY-601N1 孔删）、前壁-甲板缝加宽到 4×9（x −21.1..−17.0 × |y|≤4.5 × z 119..121.2）；`head.py` H03 浅槽两道挡边穿 Ø5 起子孔 (58.75, 0, 235.615) x 51.5..66（N07），H01 前立板顶角 2 个 7×4.4 开口缺口（x 46.5..52.5 × |y| 16.8..23.8 × z 257.6..262）。
数据（`hr29_sync_data.py`）：features T01-F20 改孔位、新 T01-F30（cable_channel）/ H01-F17（slot ×2）/ H03-F10（tool_channel），counts 248（T01 30 / H01 17 / H03 10）；parts 三件 feature_count；frozen imu_pose our_mounting_pos (−23.1, 0, 111.65)、delta (−2.1, −0.0664, 6.35)，site 不动；components `imu_icm42688`（id 不改，引用太多）内容换 Adafruit 4438（envelope 25.4×17.78×4.6、1.7 g、SH 侧插、keepout、insert_dir），新增 `cable_qt_dupont_m`（150）/ `cable_dupont_ff`（400，撕 4）；keepouts KO17 实测净空 9.9 零位 / 6.7 扫掠（checked_offline）；harness HB05 4 芯、segment_len [150, 400]、route_polyline（缝→中央通道→KO18→口袋→颈→头→H01 缺口→pin 3/4/5/6）、rules、route_unverified；fasteners F26 M2×5 ×2 @ (−23.1, ±10.16, 111.65)、装 L01 之前；assembly 步 10/19；head_specs.json head.py 指纹。发布目录：多出的 `B02_tail_tray.stl` 移到 `_旧版_hr15_2026-09-19_勿用/`（hr28b L0 `_release` 红的原因）。Gate hr29b ✅120 ❌393。

## 2026-09-21 hr28 —— 转接板进头里（用户定，方案 b：保留 Radxa 排针），B02 尾部托架作废

几何：`head.py` H03 地板下 1.5 壁浅槽（H03-F08 口袋 x 53.8..63.8 × |y|≤21 × z 226..240，槽底外 224.5）托住竖放的转接板（占位 zz_adapter x 54.3..63.3 × |y|≤20 × z 226.8..256.8，挂 jaw_soft），Radxa 排针带（z 258–263）压住板顶；通风槽（H03-F09，09-17 起未登记，本轮补）随槽底下移；`build.py` 不再 build B02；`trunk.py` B01 门顶不再开 B02 底孔。数据：features 删 B02-F01..F04 / B01-F08，counts 重算（245）；parts 删 B02、motion_instances zz_adapter→jaw_soft；fasteners 删 F31；components bus_adapter housed_by H03 + envelope [9,40,30] + 新增 cable_ph20_ext；keepouts KO12 exempt / KO01 unknowns；relations/assembly/printability/bench；harness HB01 根在头里（S1 头→头链 + 延长线→S2 口袋→S3/S4/S5 躯干），HB03/HB04/HB09 路径，链尾压降 0.71→1.11 V、fallback 改躯干就地注电；manifest body_for_part。起因：训练 MJCF（hr12，09-17）不含 B02/转接板，仰躺起立先着地；原版 HAT 在头里叠在 Pi 后。脚本 `hr28_sync_data.py` / `_part2.py`。

## 2026-09-21 —— 线翘 4 mm（hr23 → hr24）：插座让位全部改通窗，颈俯仰单挂

hr24 修正（hr23 全链 ✅117 ❌392 → 复核后改）：wire_clr 0.5 → **0.4**（A 区上沿 −17.4 = L07 6700 座环端面，座环不削）；N02 脸颊**不加厚**（外移 3.05 撞 H03：走路 106 姿态 / 头横滚 −25° 22 mm³）、改为按线翘区扫掠把脸颊下半截挖穿，F14b 回 M2×6 / 叠厚 3.40 咬 2.60（hr26 复审 F-04：09-14 惰轮端面 −12.85→−13.0 后旧值 3.55/2.45 一直没更新，本轮改正）；
T03 让位 grow 0（壁留 1.0）；N01 +y 窗开到板边 + 窗-孔薄环挖掉（N01-F10 min_dirs 22）；KO01 的 **W 只对载体查**（asmcheck / l3_static solid_targets）；sweep_cut 三条的 pos 改切除区内部点。

hr25 修正（hr24 全链 ✅122 ❌393，vs hr22b 只多 1 红 L2 N02-F12:diameter Ø15.58）：N02 `wire_clr` 的膨胀 DILATE6 → **`mink=True` 连续长方体**（`lib.conn_hump_sweep` 加 mink 透传）—— DILATE6 沿毂轴（= 扫掠轴 y）的两个副本不缩 Ø15.6 扣柱孔，A 区端面 −17.4 到脸颊外表面 −17.5 那 0.1 只有 Ø15.6 的孔 → 毂外留 0.1 厚 × 0.3 宽的唇 + 斜向 ≤0.09 薄片（L1 N02 薄区 73.9 → 80.1 mm²）；mink 后毂外干净、多削 5.3 mm³ 皮。`features.yaml:N02-F14` spec/grow_method/removed_mm3 246 → 252 重登（hr23_sync_socket_features.py 加 mink 字段）。

hr26 修正（hr25 全链 ✅121 ❌394：唇没了，但冒出 L0 N02 退化面 2 / 非流形边 2、L2 N02-F12 present 10/24 + bore_gauge 判不了）：① `neck.build_neck_pitch` wire_clr 的 idler_keep **Ø15.0 → Ø14.96** —— mink 后扣柱孔在斜向缩进毂里，扇区内刀的内壁 = keep 柱 64 边形，与毂 64 边形整面重合，导出 float32 塌成退化面；小 0.04 = 刀比毂面深 0.02，扇区里毂 r 7.48（N02-F13 Ø15.0 ±0.1 内，L2 diameter 仍量到 Ø15.0000）。② `features.yaml:N02-F12`（−y 脸颊共用沉坑）判据从 cylinder 整圈壁改 **prism 占位**（Ø15×1.1 必须空；48 边形 r 7.4，box_export_local 给 L1 禁撑区）：脸颊挖穿后坑壁只剩扇形板那 ≈150°，hr24 的 24/24 是 DILATE6 的唇在充数；nominal_d/depth 保留给 L5 螺丝头判据。③ N02-F13 note、N02-F14 spec 跟着重登。预检：`gate.py --layers 0,2 --parts N02` L0 三条绿、N02-F12/F13/F14 全绿。

hr27（hr26 独立复审 `hr26_review.md` BLOCKER 0 / MAJOR 2 / MINOR 10 后的数据与检查体系修正，**几何不变**）：① F-01 发布包 `01_整鸭打印件/` 顶层 24 个 hr15 旧 STL + assembly_preview 归档到 `_旧版_hr15_2026-09-19_勿用/`；`l0_mesh` 加 **`_release:release_root_no_duplicate_stl`**（根目录无 STL；非留档子目录里同名件必须同 sha；名字带 旧版/勿用 的目录不查）。另发现 09-17 退役的 L08/L09/L11/L12 四个 STL 一直留在 cad/duck_s288/ 并被同步脚本通配符抄进 S288专用件/ → 移到 `cad/duck_s288/_retired_2026-09-17/` 与留档目录，`export_vs_release_sha256` 加"发布副本多出（不在 parts.yaml）也红"。② F-02/F-03 `harness.yaml:HB01` S5→5 / S5→6 / 6→7 三跳标 `route_unverified: true` 并写明走廊探针结论（N01 −y 面外侧在 neck_pitch ≥ +30° 被 T03 壳顶压住，线只能走壳外）；`keepouts.yaml:KO01.unknowns` 加两条显式缺口（线翘体不在 L6 组合/真实姿态里；三跳走线未验证），第 1 条"脸颊外移"改口；HB01 链 F why 同。③ F-04 `fasteners.yaml:F14b` stack 3.55 → **3.40**、engagement 2.45 → **2.60**（hr26 件射线 6/6：沉坑底 −16.40 → 惰轮端面 −13.0；09-14 端面改 −13.0 后一直没更新），`features.yaml:N02-F12` purpose/nominal_source 同步。④ F-11 反例 `n_l3_ko01_neighbor_zone.py`：邻件闯 A 必须红 / 邻件只在 W 不许红 / 载体在 W 必须红。⑤ F-12 `head_specs.json` neck.py 指纹刷到 hr26（head audit 0 FAIL）。⑥ F-07/F-10 记录口径改正。未做（MINOR，可选 CAD）：F-05 L07 座环缺口 ≈1 mm² 皮、F-06 N02 脸颊边 4.9 mm² 楔、F-09 wire_out 卡尺值（等实物）。

- `keepouts.yaml:KO01`：dims **wire_out 2.0 → 4.0（measured，用户实物目测：原配线硬、出插头先直立 ≈4）+ wire_clr 0.5**，A 区 x −17.5..−13.0；pocket 型作废；
  rows 9/10（踝）前口 window / 后口 none（L07 后臂 +90° 扫过 37/80 mm³）、row 11（颈俯仰）+y window / −y none（T03 +35° 7.1 / T01 +60° 0.9 mm³）、row 12（头俯仰）两口 window
  （N02 −y 脸颊外移 3.05）；status_detail 23 查 + 5 不查；motion_caveat 改成 asmcheck `socket_motion` 单关节扫掠；unknowns 缺口 y/z 改"按图纸为准（用户 09-21）"。
- `features.yaml`：删 L01-F15/16、L04-F15/16、N01-F11..14（hr16 口袋/板角 8 条），重登 L01-F15/16（板角削，深 4.2）、L04-F15（踝前口窗）、N01-F11（颈俯仰 +y 窗）、
  N01-F12/13（头俯仰两窗）；新增 sweep_cut **L07-F11**（后臂减线翘区绕踝反向扫掠，hr22 件切 73.6 mm³）、**N02-F14**（−y 脸颊减线翘区绕头俯仰反向扫掠 [−92,56.2]，内层通槽）、
  **T03-F08**（壳减颈俯仰 +y / 头俯仰两口线翘区绕颈俯仰扫掠，16.6 mm³）。by_kind window 11→15 / cable_channel 9→3 / sweep_cut 12→15；247→248。生成脚本
  `docs/design_2026-09-17_bearing_rebuild/hr23_sync_socket_features.py`。
- `fasteners.yaml:F14b_headpitch_idler`：M2×6 → **M2×8**（脸颊加厚 3.05，−y 侧沉坑 1.1 → 2.25，叠厚 5.3，咬 2.7；长度规则 8 ≤ 5.3+3.0−0.3 = 8.0 刚好）。
- `harness.yaml:HB01`：topology daisy_chain_5 → **daisy_chain_6_branches**：踝改前口（3→4 零位 44.8）；颈俯仰只剩 +y 口 → 单挂（链 E），头链 F（头俯仰 +y 进 −y 出 → 头偏航 −y 进 +y 出 → 头横滚）另起，
  一分二 **4 → 5（S5 放顶板口袋）**；L_EXIT 2 → 4；worst hop 93.9 ≤ 150。
- `components.yaml:bus_splitter` qty 4 → 5（购物车待改）。
- `parts.yaml` feature_count L04 −1 / N01 −1 / L07 +1 / N02 +1 / T03 +1，features_total 225 → 226。
- 工具：`tools/cad/asmcheck.py` 新增 `socket_motion`（window/free 口线翘区逐单关节 target_range 5°/档 与不同 body 件求交，--from-placed 时跑）；
  `tools/gate/layers/l3_static.py` KO01 加 wire_clr_mm。

## 2026-09-20 晚 —— 电子件安装位（hr17/hr18）：B02 尾部托架、T02 开关面板、T01 扎带环登记

- `parts.yaml`：新件 **B02**（tail_tray，底板朝下）；`motion_instances` 加 tail_tray / zz_adapter（转接板占位）→ trunk_base；counts.parts 24 → 25。`printability.yaml:parts.B02`。
- `features.yaml`：frames.per_part.B02；hr16 插座让位 16 条 prism void（T01-F27/28、L01-F15/16、L03-F07..10、L04-F15/16、N01-F11..14、N03-F11/12，`hr16_sync_socket_features.py`）；hr18 加 B02-F01..F04（过孔/口袋/底板/扎带槽）、B01-F08（门顶条 Ø1.7 底孔）。
- `fasteners.yaml`：**F31_B02_to_B01** 2×M2×6（穿凸台 3.5 进门 2.5，尖端离门内面 0.5）；坐面探针/feature_hole_map 未登记（L5 红，待 probe_seats）。
- `assembly.yaml`：步 16 带 B02（门+托架一起 +x 推入；required_motion_groups 与 motions 的 battery_door movers 都加 tail_tray/zz_adapter；parts 加 zz_adapter；所有含 battery_door 的 present 补两项）；拆序 4 movers [B01, B02, zz_adapter]。
- `keepouts.yaml:KO12` exempt 加 B02（抽出走廊段，随门拆；仓腔段不豁免）。
- `relations.yaml:parts_without_declared_load_path` 加 B02（只托转接板，不在传力链上）。
- `components.yaml`：bus_adapter housed_by B02 + claim placed_prefix→zz_adapter + envelope_solid 30×40×9；switch_rocker 定位 T02 壳顶（KCD1-101 21×15×20）；buck_12v_5v → 航模 UBEC 5V/3A（T01 −y 侧腔）；新增 connector_wago_221_412 ×5；display_lcd qty 0（09-19 取消）。counts 23 → 24。
- `harness.yaml`：HB03（12 V：电池→开关→转接板）/ HB04（5 V：拓展口→UBEC→40 针）走线按新位置重写。
- `tools/sim/cad_geometry_manifest.json`：body_for_part 加 tail_tray / zz_adapter（漏了它 hr17 第一次跑运动审计/真实姿态开头就炸）。
- hr17b Gate ✅114 ❌404 → hr18 见 `docs/design_2026-09-17_bearing_rebuild/记录.md` 第 25–26 条（新红逐条归因：未实测/未探针/组合极限）。

## 2026-09-20 —— S288 插座模型改为背插（hr16）：KO01/HB01 重写，串联 5 条链

- 事实：用户舵机到手拍照，两个 PH2.0 座在**背面（惰轮面）接线端两角**的缺口里、针朝 −x、插头沿 x 从背面插，插到底与厚段 23 面齐平，只有线再凸 1–2（口径 23–25）。09-11 拿手册尺寸图逐像素反推出的"侧插（±y）/ 10 颗只有 1 口 / Y 线分接"整套作废（docs/design_2026-09-17_bearing_rebuild/电子件尺寸核实_2026-09-19.md §8）。
- `keepouts.yaml:KO01` 整条重写：实体 = A 插头顶/线弯区（x −15..−13 × |y| 5..10.5 × z −14.4..−4.2，扣 Ø15.6 惰轮毂柱）+ B 侧出线槽（|y| 10..13.3）/ W 背板通窗（x −18.5..−13）；逐颗逐侧 `mode_pos_y/mode_neg_y` ∈ {pocket, window, free, none}（与 `duckstructure/lib.py:CONN_MODE` 同表）。dims 新键 plug_top_x/wire_out/plug_clr/plug_y_in/side_exit_y/window_x/hub_keep_d；旧 window_face_grid/probe_offset、socket_center、recess_depth、plug_protrusion、pull_clearance、cad_fix_required CF1–CF5 删（历史进 geom_superseded）。status checked_partial → checked。
- `tools/gate/layers/l3_static.py` KO01 段按新 dims 建实体（查全部打印件，none 侧不查；CAD `conn_cut(R, sides, mode)` 只作对照，同侧 A+B/A+W 并起来比）；`window_face` 判据随侧插模型一起退役。反例 `n_l3_ko01_independent` 改成：声明通窗加深到 −25 而 CAD 只切到 −18.5 → 独立实体 64 mm³ 红；pocket 模式侧出线槽里的料红、同料 window 模式绿；dims 缺 unknown —— 通过。
- `harness.yaml:HB01` 拓扑 bus_tree_y_tap → **daisy_chain_5_branches**：转接板 PH 座 → 4 根一分二（S1..S4）→ 左腿链（髋横滚→髋俯仰→膝→踝）/ 右腿链 / 左髋偏航单挂 / 右髋偏航单挂（外侧口压在冻结壳柱下，只有 1 口）/ 颈头链（颈俯仰→头俯仰→头偏航→头横滚）；每跳 1 根舵机原配 150 mm 壳-壳线（14 用 1 备），零位跳距 19–63、估全行程上界 +9；pin_order 转接板侧实测 SIGNAL–VCC–GND（B 版）；供电全经 PH 座（宇树设计），A 口径 4.48 A > 2 A 额定 → BN02 实测定，fallback 分链注电保留。
- `components.yaml`：`bus_adapter` 四口位置与公母（09-20 实测：PH 座 + XT30(2+2) 公一端，XT30 入口公 + Type-C 一端，均短边侧出）、拟装尾部模块；`cable_ph20` 改为原配线 15 根 + 新增 `bus_splitter`（一公分二母 ×4）；`servo_s288.pinout` 加转接板侧实测旁证（v 仍 null 到 BN16）。counts.components 22 → 23。
- CAD（hr16）：`s288.py` conn_x/plug_top_x/wire_out/plug_y_in；`lib.py` CONN_MODE/conn_zone/conn_cut；L01 削板角、L03 四口通窗、L04 两口口袋、N01 四口口袋、N02 −y 脸颊线弯区 ±45° 扫掠让位槽、N03 两口通窗（裙墙不再开口）、H01 去掉头横滚刀与 CF3 走廊、H03 去掉可见孔、T01 顶板内侧口通窗。`tools/cad/asmcheck.py` 插座段按 CONN_MODE 查 A/B/W 对全部 placed 件。
- `assembly.yaml` 步 12：偏航舵机 CF3 插头改为装好后从背板通窗插（"先接好"不再必要）。

## 2026-09-18 凌晨 —— Gate 三次全量后的装配数据修正 + Gate/采样并行

- `assembly.yaml`：run1 后补 27 处 `present` 缺项（新轴承/轴套/头部四新件）；run2 后步 6 parts 去掉 6703/L10（轴承+轴套不与舵机同装），步 8 新增 `L/R_pitch_bearing_sleeve_into_L03`、`L/R_roll_bearing_sleeve_into_L01` 4 条推入动作（present = 全步在场集），`hip_onto_roll_flange` movers 加俯仰轴承+轴套；步 14/15 头部新件加入 movers（随头动）；`tool_states.headroll_flange.after_motion` → `h_roll_servo_into_N03`、present 改 N03 台架在场 9 件。步 11 d（N06 进腔）保持 known_fail（真几何，hr13）。
- `tools/gate/gate.py --jobs`、`tools/sim/policy_pose_collisions.py --jobs`：按层/按姿态段并行（记录.md 18），结果与串行逐格/逐行相同；L6 `_REAL_POSES` → `policy_steps_2026-09-17_hr12b`（并行重采样，poses sha 与 hr12 相同）。
- run4（并行，10.8 min）后再修：步 8 `6704×1`→`bearing_left_knee/right_knee`、步 11–13 `6704(yaw)/(A)`→显式实例（型号→外径解析会把头部 6704 算进腿步，present_covers_derived 假红）；4 条轴承+轴套推入动作加 `subassembly_of`（俯仰 upper_leg / 横滚 trunk）+ 物理正确的 present（L02 不在场）；横滚推入 len 20→60、N07 12→40（末端脱离证明）。**L4 step08 PASS**；step11 只剩 N06（真几何）。
- 记分卡：run3 ✅112 ❌398（`docs/gate/gate_full_2026-09-17_hr12.log`）；并行全量最终 ✅108 ❌402（`docs/gate/gate_full_2026-09-18_hr12_parallel.log` RUN 4：`tool_states.hippitch_flange_L/R` 补俯仰轴承+轴套；L6 `_REAL_POSES` → `policy_steps_2026-09-18_hr12c`，采样指纹有效，`real_pose_collisions` 从 unknown 变为实判 1514 姿态 / 17 对 = 之前 unknown 那 6 格转为实红；相对 run1 无任何格由绿转红）。

## 2026-09-17 夜 —— 轴承恢复 hr12 收尾：豁免绑 STL、L6 指 hr12、6703 质量、头部装配顺序按新序重写

- `waivers.yaml` 第 3 条：绑上 `cad/duck_s288/L03_upper_leg.stl` / `T01_trunk.stl` 的 sha（hr12 build）；hr12 真实姿态对比该 body 对 1 姿态 / 0.099 mm³，与豁免一致。
- `tools/gate/layers/l6_motion.py` `_REAL_POSES` → `tools/gate/out/policy_steps_2026-09-17_hr12/summary.json`（placed 指纹已核）。
- `components.yaml` `bearing_6703zz.mass_g` 4.2 g（目录净重；实心环 5.92 g × 71%，与 6704 的 72.7% 同量级；到货称重替换）；`bearing_6704zz` 加 `stale_keys_note`（取消口径的旧键只作历史）。`tools/sim/make_mjcf.py` 髋横滚/髋俯仰轴承按 6703 计，四份 MJCF 重出（整机 762.7 g）。
- `assembly.yaml` 步 11/12/13 **按 hr11 新顺序整体重写**（不再只是 note）：步 11 = N03 台架子总成 10 个分动作（偏航 6704 → N08 → N02 轴颈 → N06 → B 22×16×4 → A 6704 → N05 → 横滚舵机 → N04 → N07），步 12 = 偏航舵机 −y 横进 + F15/F16，步 13 = H01 从上套下 + H02（F18/F19）；present 按累计在场（F-L4-1），方向/长度来自 mechanical_audit paths + 全序累计扫掠（14/15 条 0）。
  **已知红**：步 11 `d_N06_into_cavity_onto_journal`（N06 Ø21.6 抬 4–5.5 后沿 −y 出腔口与 N03 交叠 ≈5 mm³）——N06 进腔路径以前从未检查过，hr13 在 neck.py 给 N03 减掉该扫掠。`subassemblies.head` note 同步。
- `fasteners.yaml` F29/F30：删掉从 F19 抄来的 `tool_access_probe_2026-09-13` 与 pilot 块（Ø1.6/4.5/H01-F12），改为 N04/N03 耳的 Ø1.7 / 5.4 / 5.3（design）、`drive_direction` 改正（+x 经 H01 前板孔 / 下方 −z）。
- 发布目录 `01_整鸭打印件/S288专用件` 同步 24 件（L0 `export_vs_release_sha256`）、`06_CAD源码/duckstructure` 同步；打印清单重写为 hr12 版。

## 2026-09-17 —— 轴承恢复 hr10/hr11：装配顺序改写、F06 平垫、髋两站不加压盖（用户拍板）

- `assembly.yaml` 步 11/12/13：加 `hr11_order_note`（不改原字段，`verified: false` 不变）：头部新顺序 = N03+N05+A 轴承+横滚舵机(F17，腔空)+N04/B 轴承/N07 →
  偏航舵机 **−y 横着滑进** N03 → **H01 整个从上套下**（H01 去掉笼底板 `lower`）→ H02 → N02/N06/F16 从下 → H03。依据 `docs/design_2026-09-17_bearing_rebuild/记录.md` 15。
- `fasteners.yaml` F06：加 `washer_2026-09-17`（L02 俯仰盘 180° 那颗坐面 61/72，加 Ø4.5×0.5 平垫 ×2，采购清单同步）。
- `waivers.yaml` 新增 WARN 豁免 `L6/L03:real_pose_collisions:trunk_base×upper_leg_left`：1/5601 姿态 0.10 mm³（左髋横滚 25.5° > 关节区间 ±22°；修它要把 6703 座壁削到 <1.1）。用户 09-17 拍板接受不改件；STL sha 等 hr12 补绑。
- `tolerances.yaml:servo_output_bearing`：宇树客服 09-17 17:29 答复「输出端轴承，另一个侧是衬套」→ 记 support_reply，v 仍 null（无额定值）；问题清单同步。
- 髋横滚/髋俯仰 6703 外圈 +x 侧不加压盖：座唇 + 舵机堆叠定位（与膝 6704 同），BN08 装配时量轴向旷量，>0.2 mm 补厌氧固持胶（记录.md 15）。

## 2026-09-09 —— 给 Gate 第 2/5 层补机器可读几何（数据修补，不动检查器）

改动只落在 `features.yaml` / `fasteners.yaml` / `relations.yaml` / `tolerances.yaml` + 本文件。
12 个 YAML 全部 `yaml.safe_load` 通过；逐键对比修改前后，**原有字段一个没丢**，只有下面明确列出的 11 处原字段值被改。

### 1 · `features.yaml`（缺陷 ①②⑧⑨）
- **新增顶层 `frames:`**：`export_local` 的定义（= `checks.py:17-19 export()` 的 `to_local`，即 `inv(TW(body))·p_world`）、
  三种旧 `datum_frame` 到它的变换、17 个件的 `world_to_export_local_R/t` + 导出 STL 包围盒、19 个舵机帧的
  `servo_to_export_local_R/t`，以及 8 个件的射线核验结果。
- **151 条特征全部新增 `geom:` 段**（只增不删）：`shape / nominal_d_mm / depth_mm / depth_kind / through / axis / pos /
  axial_span_mm / bbox_mm / hole_positions_mm / count / pitch_r_mm / frame / frame_note / derived_from / confidence`，
  坐标与轴向**全部改写到 `export_local`**。数值全部从 `duckstructure/*.py` 与 `tools/cad/ankle_split.py` 抠，不从 `spec_verbatim` 反推。
- `confidence`：`exact` 126 / `derived` 23 / `unresolved` 2（`L06-F04` 鞋底 4 孔、`H03-F02` H01 四脚接收孔，
  两者都是 `not_modeled`：原版网格里的孔，代码没建模也没量过，**不编**）。
- **53 条特征做了导出件射线核验**（`verified_on_export`，读 `cad/duck_s288/*.stl`，沿轴 17 站扫描），全部通过，
  这些条目的 `nominal_d_mm.src` 因此升级为 `measured`。另有 12 条标 `pass: null` + 原因（法兰让位开在自由端面、
  环形刀轴心被毂占住、凸台埋在实体里 …），**不当反证**。
- 缺陷⑧：8 条 `horn_hole` 全部补 `pitch_r_mm = 4.75 (measured, s288.py:19)`（原来只有 `L01-F04` 在自由文本里写过）；
  60 条孔类特征里 57 条补齐 `through` + `depth_mm`（`depth_kind` 区分刀长/盲深/实体厚度），剩 3 条见上面的 unresolved / 多实例条目。
- 缺陷⑨：8 条 `horn_hole` 各加 `clock_phase: {declared_deg: null, datum: null, unknown_class: not_selected,
  must_declare_before: 装配, blocks_relation: R23}` —— **代码里确实没有相位约定，没编**。

### 2 · `fasteners.yaml`（缺陷④）
- **30 组全部新增 `feature_ids` + `feature_hole_map`**（含每颗螺丝在 `export_local` 里的孔坐标）。
  29 组有孔坐标；`F23_sole_to_foot` 没有（唯一目标 `L06-F04` 未建模）。
- N01 那 6 个背孔按孔位拆清楚了：`F11` = `N01-F06` 上排 2 个（索引 0/2）、`F11b` = `N01-F06` 下排 2 个（索引 1/3）、
  `F13` = `N01-F07` 的 2 个，三组互不重叠。
- 8 个自攻组新增 `pilot` 段（`pilot_hole_d_mm` / `pilot_depth_mm` / `declared_in_feature`），
  从 `joins` 自由文本抠出并与源码逐条核对；`F22`/`F23` 保持 `null` + `not_modeled`。

### 3 · `relations.yaml`（缺陷③⑨⑩）
- 缺陷③：`R09` → `engagement_by_joint_type.s288_metal_thread`；`R10`/`R20` → `engagement_by_joint_type.pla_self_tap`；
  `R12` 指的 `fits.axis.concentricity` 桶本轮在 `tolerances.yaml` 里真的建出来了（区间引用已存在的 `datum_vs_mjcf_mm`，没新编数）。
- 缺陷⑨：**新增 `R23`（舵盘零位相位未声明，status=open / BLOCK）**，会一直判红直到有人定下基准。
- 缺陷⑩：`counts` 补 `open_definition` + `open_relations / open_gate_entries / open_total(19) / ok_relations` 与各自的 id 列表。
- **改了原字段值**：`counts.relations 22→23`、`counts.open 15→16`（因为加了 R23，必须与列表长度自洽）；
  `R09/R10/R20.target_ref`（悬空→实际键）；`R18.between[1]` `2.6×2.4×3.4`→`2.3×2.4×3.4`（x 向记错，见下）；
  `R06.note`/`R10.note` 各追加一句指针。

### 4 · `tolerances.yaml`（缺陷③⑤⑥⑦）
- 缺陷⑤：`fits.pla.plain_slide_head_roll` 拆量纲 —— 原 `nominal_mm`(直径) 与 `target_range_mm`(单边间隙) 都保留并各加
  `*_quantity`，新增 `nominal_d_mm` 与 `radial_clearance_mm`（discA/discB 分开，名义值与实测值分开），
  并把 `conflicts.seat_d` 那句"必须按 0.09 判"变成机器可读的 `gate_must_use`（discA 0.09 / discB 0.29 + `verdict`）。
- 缺陷⑥：`fits.snap.b01` 新增 `compare_field: protrusion` + `compare_value_mm 1.0 (measured)` + `compare_note`。
- 缺陷⑦：长度公式的唯一权威定义留在 `screw_length_rule`（新增 `authoritative: true` / `tip_margin_mm` /
  `blind_depth_by_joint_type`）；`engagement_by_joint_type.*.rule` 两条**改写成引用**（原字段保留，只改值）。
  `pla_self_tap` 另加机器可读的 `violations / satisfied / unknown`。
- 缺陷③：新建 `fits.axis.concentricity`；`placeholder_summary` 计数 21→22 并补上该桶。
- 新增 3 条 `conflicts`：`deck_keyhole_clearance`、`L01_hiproll_counterbore_d`（见下），`seat_d` 补 `gate_must_use` 指针。

### 5 · 抠代码时发现 `features.yaml` / `relations.yaml` **原本就记错**的条目（全部已登记，未静默改判据）
| 条目 | 原记 | 实际（源码 + 导出件射线） |
|---|---|---|
| `L05-F07` | 2×Ø4.6 起子通道属于 **L05** | 属于 **L07**：L07 STL 在舵机帧 x −19..−17 处 36/36 向命中 r=2.2973；L05 整个 x 区间量不到 |
| `L01-F09` | 沉孔 Ø4.2 深 1.25 | 有效沉孔是原版自带的 **Ø4.84**（36/36 向 r=2.4200），我们的 Ø4.2 刀全落在里面，不产生新坐面 |
| `T01-F20` / `F26` / `R10` | IMU 底孔"深 10" | 前壁只有 **3.5** 厚且孔直通电池仓 → 自攻咬入上限 3.5 < 2×d=4.0，`pla_self_tap` 不满足的是 **3 处**不是 2 处 |
| `T01-F16` / `F21b` | 仓门底孔 count 2 | x=−44.5 那颗**没有接收料**（24 向只 5 向命中），已加 `effective_count: 1` |
| `T01-F09` / `R21` / `fits.deck.keyhole` | 甲板钥匙孔单边 2.35 | 成品件上被载体前板堵住，有效孔是 Ø14.9 滑槽，单边 **0.49**（z 119.2..121.2 全程 r=7.441） |
| `R18` | L07 榫槽 2.6×2.4×3.4 | **2.3**×2.4×3.4（`ankle_split.py:49` −13.6−(−15.9)=2.3）；间隙 0.2 的结论不变 |
| `T01-F22` | 壳柱高 8.9/10.7 | 那是**左半壳**两根；右半壳是 9.1604/10.8431（`shell_inner_z` 逐根射线量） |
| `L05-F08` | 扫掠 ±37 n75/n11 | 现行代码是 **±62**，舵机包络 n=125、小腿 n=21（`lib.py:24`） |
| `conflicts.seat_d` | 壳座 r10.89 | 导出 H03 半座最小内半径 **10.9000**（间隙 0.10/0.30）；仍按 0.09/0.29 保守判 |
| 多条 `datum_frame` | `part_local` / `world_verbatim` | 实际是舵机帧（如 `L01-F01/F07/F09`、`L05-F07`）；逐条写进 `geom.frame_note` |

## 2026-09-12 —— Gate 清红第一批（检查器与数据，未改 CAD 几何）

- `parts.yaml` 成为 52 个 placed 实体运动归属的唯一声明；补入 N04、头横滚 B 轴承、左右髋偏航轴承。18 件逐项列出 `placed_instances`，按 BOM qty、唯一性与文件存在校验，修复 `rstrip('_R')` 导致的不确定左右查找。`cad_motion_check.py snapshot` 已刷新；快照只记录身份，不能代替运行检查。
- L1 禁撑孔支持 `positions_mm`，嵌套组明确 `count_kind`，组数/孔数/总柱数均校验；缺组、缺孔、重复组、不有限坐标不能缩小检查全集。补 B01-F04、H01-F09、T01-F16/F19/F20 轴向段；69 条禁撑特征中 66 可定位，余 L01-F13/L03-F05 是非柱形装入廊道，L06-F04 未量，继续失败。
- H03-F02 四孔身：432 条径向射线，Ø2.1999937245..2.2000034450 mm；前三总盲深 10.0（含 0.7 扩口），第四底口通壳腔，无统一盲深。新增 H03-F04 的四段 Ø2.8×0.7 扩口禁撑。L5 `self_tap_radial_overlap` 得 F22 `(2.0−2.2)/2=−0.1 mm`，明确为自攻不咬合，不能说补数据后就没问题；未改孔或换螺丝。
- 修正 KO06/KO07/KO09/KO11 的坐标帧声明。未通过改实体或放宽阈值消红。
- L4 的 1/2/3/4/6/7 共 6 步、14 条刚性子动作，分左右工位，固定移动组、在场全集与抽出向量；独立 `required_motion_groups` 防删路径/删障碍。0.25 mm 步距，含精确终点，14 条逐件 STL 探测共 7,260 次证据，最大交集 0.0004162917 mm³。该数不证明连续运动或整机拆卸可行。
- 起子检查迁到 `tool_access.py`：头侧孔身份、真坐面、轴向、足印与拧紧工位均显式声明；批杆 `bit_d_mm`、可用杆长 `available_shaft_len_mm` 与旧通道/需求下界分开。缺声明的其余 27 组判 unknown，取消从孔中点/沉坑直径产生的假几何结论。F01/F24 共 8 坐面 1,152 次足印内外探针全过；工具峰值分别 0、1.58e-15 mm³，可用杆长仍未知。
- F01 旧 129.67 mm³ 实际撞未安装的头壳，不能解读为“被自己的孔挡”；F24 的旧世界 −x 实为舵机局部 −x，左世界 −y/右 +y。新增刀路只证明相应工位安装，整机维修拆卸仍独立判。
- 六个新反例模块覆盖上述漏检；旧 L4 反例只补新的 BOM/真坐面/工具规格声明，保留原始坏几何。22 个反例全过；运动检查器 18 项 unittest 全过。独立复审两轮发现的 MAJOR 全修，已审范围 0 BLOCKER/0 MAJOR；这不代表整机放行。
- 完整 Gate 结果与后续待办见 `tools/gate/out/scorecard.md`、`docs/README.md`；运行日志 `docs/build_logs/gate_2026-09-12_cleanup.log`。分度圆停线、所有实机未知和冻结项仍保留。
- 完整 Gate 首跑 1795.2 s：76 PASS / 363 FAIL / 1 STALE / 7 NOT_RUN，2073 条判据中 915 FAIL；401 条红无测量（旧为 375），不是物理缺陷减少。相对交接的 70/378：6 个装配步骤完成验证，新增覆盖门槛；4 个旧 L4 绿格因缺真坐面改红，9 个旧起子错误归因的件级格子撤掉。所有 140 个运行输入前后 hash 一致；无 NaN/Inf 测量、无 evidence_n=0 的 PASS、无层执行异常。
- 随后补 L2 镜像数值防护：单方向 NaN/Inf 或无采样点必须失败，防 `max(有限值, NaN)` 隐藏失败；新反例正常双向距离最大 2.52e-15 mm，NaN/Inf/空方向均拒绝。仅复跑 L2（依然先跑全部反例），其余层沿用已绑定 hash 的完整运行结果。
- L2 正式复跑完成（`docs/build_logs/gate_2026-09-12_cleanup_l2_finite.log`，1239.7 s，含全部反例）：**23/23 反例通过**，605 条 L2 判据 / 187 条红；最终汇总仍为 76 PASS / 363 FAIL / 1 STALE / 7 NOT_RUN、2073 条判据 / 915 FAIL（401 条无测量）。退出码 1 表示整机 BLOCKED，不是执行崩溃。
- 最终复核：7 对镜像各 2400 点有效，18 个 STL 洞边全 0；137 个格子输入文件 hash 全部匹配磁盘，无非有限测量、零证据 PASS 或层执行异常。`L6/_joints` 唯一 STALE 是主动撤销“必须等于上游限位”的权威，未改限位；其余未重跑层以输入未变沿用。独立复审第 3 轮确认 L2 防护范围内 0 BLOCKER/0 MAJOR。

## 2026-09-12 —— Gate 清红第二批（进行中，用户中途叫停；详见 docs/交接_2026-09-12_Gate清红.md §8）

- L4 `judge_fixed_path` 支持 `segments` 多段直线（首尾相接，终点脱离证明用最后一段方向）；反例 `n_l4_segment_end_inside`。
- assembly.yaml：步骤 5/8/9/10/11/12/13/14/15/16/17/18 共 36 条 `motions` + `required_motion_groups`，`tool_states` 24 个；step 6 工位改为 L01 已在躯干上；step 9 重写为偏航舵机侧滑（旧"腿子总成"与 F02 从杯腔拧矛盾，作废）；step 18 记录原版上/下头壳合缝相交 67.894（冻结件，H03 侧让位已进源码）；step 19 标 not_modeled。**尚未跑 L4 正式扫掠。**
- features.yaml：L06-F04 实测导出网格 0 孔（absent_in_model）；L01-F13 / L03-F05 新增 `box_export_local`（servo_slide 实体外包盒）；被 dump 吃掉的 rib_probe 说明注释移到文件头。fasteners.yaml：F23 status=no_geometry；头部注释补回。keepouts.yaml：KO07 顶 224.3→224.26（=ZF−NP_DISC_T）；KO01 说明注释移到头部。
- L1：`_feature_boxes/_box_section` 盒形禁撑区；`min_wall_sliced` 改用 `layers_single_bead`（Arachne 双 bead 墙不再误判单圈；旧记录缺该字段 → unknown）；反例 `n_l1_support_in_box_zone`、`n_l1_single_bead_gcode`。`slicing/slice_l1.py` 解析修正（;TYPE: 跟挤出记层；外圈走线长/截面周长比值）。slice_run.yaml 只重切了 L02/L03，printability.yaml 尚未更新。
- 新工具 `tools/gate/probe_seats.py`（螺丝真坐面探针）。tool_access 27 组仍 unknown，探针后台未完。
- duckstructure 源码已改未 build：neck.NP_KO_OVER、head.KO_OVER/通道刀最后一刀、head H03 填料+Ø1.7 底孔、head HEAD_SEAM_CLR、legs L02 俯仰侧填柱 y 34.0..40.3。

## 2026-09-12 晚 —— build #7 + 参考复刻标定（docs/参考对比_2026-09-12_AI-FanGe复刻.md）

- `duckstructure.build` #7：上批源码改动（NP_KO_OVER / KO_OVER / H03 填料+Ø1.7 底孔 / HEAD_SEAM_CLR 0.1 / L02 填柱退到板内面）已出 STL、placed/、audit_summary.json、mechanical_audit.json。静态 0；`[已修接口与错相回归] PASS`；H03×原顶壳合缝 67.898 → **0.0 mm³**（`H03_original_seam.current_mm3`），H03×舵机名义间隙 0.29999；退出码 2 仍是冻结的 B01 x=−44.5 后孔未闭环 + 扫掠 268 对（同前）。三个只读检查 idlercheck / asmcheck / audit_screws 均 exit 0（`docs/build_logs/checks_2026-09-12_build7.log`）。`tools/cad/mechanical_audit.py` 的合缝检查改为容忍零体积交集（交集退化成贴合面片时不再做布尔差，直接记 0）。
- **发布目录未同步、18 件未重切片、Gate 未全跑**：PrusaSlicer 的 dmg 挂载点（/tmp/microduck-slicer-check-20260908）随关机丢失，重切要先把 2.9.6 再挂回来。
- 标定：用 L1 `min_wall_geometric` 的原判据判 16 件已实打实打出来的原版件（AI-FanGe 复刻 3MF 的朝向）→ ~~17/20 红~~ **11/16 红**（09-13 复审发现第一版朝向轴系错了，`orient_icp.py` ICP 配回原版坐标后重算；结论不变）。该判据降 BLOCK→WARN（`l1_printable.py`），证据与不改阈值的理由记在 `printability.yaml:criteria.min_wall_perimeters.calibration_2026-09-12`；`min_wall_sliced`（真 G-code 单 bead 层）仍 BLOCK。反例 n_l1_thin_wall / n_l1_single_bead_gcode / n_l1_support_in_box_zone 复跑通过。
- 措辞修正 8 处："髋偏航副支撑原版没有" → 原版 `robot_walk.xml` 在髋偏航轴上本来就有 22×16×4（舵盘面平面 z 115..119；受力报告 §4 判为推力式夹持），S288 配不了那种夹法才改法兰侧径向 6702（README、legs.py、lib.py×2、trunk.py、mechanical_audit.py×2、受力分析报告表格）。几何未动。
- 待用户定：M2 沉孔 Ø4.2 比原版 Ø4.4/4.84 紧，叠 TC02 实测缩水 0.15/边 → ≈3.9 < 盘头 4.0；靠切片补偿则够（单边 0.1）。`fits.pla.m2_counterbore` 仍 placeholder。
- 原版孔径普查（`docs/probes_2026-09-12/参考对比/holes_orig.json`）：M2 自攻底孔原版用 Ø1.6，与我们 Ø1.6/1.7 一致；原版底壳 Ø2.2 是过孔（配 Ø4.4 沉）而非自攻底孔——H03-F02 "不能成牙"的根子在此，09-12 填料+Ø1.7 已按原版惯例修正。

## 2026-09-13 —— 复审修订 + 『有则改之』（用户拍板）+ L1 标定门禁

- 独立复审（workflow verify:doc）抓出 参考对比 文档 4 处硬错：§2.1 打印朝向轴系错（OBJ 原始坐标 ≠ 原版网格坐标）→ 标定重算 11/16 红；§5-B "309 mm³ 重叠"错（annulus 放低 2 mm，实为 0 干涉、推力式夹持成立）；§5-C/D 原版头壳 Ø2.2 是 9 mm 深 M2.5 底孔（配 motor_support Ø2.7），不是过孔；"原版没有"措辞漏 7 处（components/features×2/relations/parts.yaml、assembly_audit.py、6702 实施规格、probes/audit_block.py）→ 15 处全改。文末有修订清单。
- **过孔 2.2→2.4、头窝 4.2→4.4**（用户 09-13：有则改之，不靠切片补偿）：`s288.py horn_hole_d/mnt_hole_d`，`lib.py P.m2_cbore_d / P.tube_hole_d`（driven / horn_cbore / mount_cut_local / mnt_cut2 / head H02 / neck 脸颊沉窝 / NP_CB_D 13.8→14.0 全引用它），`trunk.py` B01 门孔，`tools/cad/ankle_split.py through_d/counterbore_d`。T01 扎带孔 Ø2.2 未动。Gate 声明：新工具 `tools/gate/retarget_hole_d.py --apply` 改 features.yaml 40 处 nominal_d_mm（文本级，注释保留；跳过 T01-F19 扎带孔、H03-F02 旧底孔）；`tolerances.yaml` fits.pla.m2_through_hole 2.4（2.35..2.55）/ m2_counterbore 4.4（4.3..4.6）、`process._positioning` 口径改为"内轮廓按实测让、外轮廓等 TC01b"；`components.yaml` 两处 src_note。**未 build**，等分度圆定案（TB02 一扣）后与 horn_r 一起 retarget + build。
- **L1 标定门禁**：`printability.yaml:calibration_set`（8 件原版网格 + ICP 朝向 + max_block_fail_fraction 0.5 + checks_in_scope 8 条几何判据）；`tools/gate/calibrate_l1.py` 跑真 L1 出 `data/l1_calibration.yaml`（指纹 = process/criteria/materials/calibration_set 规范 JSON + l1_printable.py 源码；逐件 mesh sha）；L1 末尾 `_calibration/proven_parts`（BLOCK）：记录缺/指纹不符/网格 sha 不符/范围未声明 → 红；范围内任何 BLOCK 判据失败比例 > 0.5 → 红（unknown 不计分母，print_orientation/slice_freshness 是簿记，范围外只报不判）。当前记录 2026-09-12 23:35：min_wall_geometric[WARN] 5/8、support_reachable[WARN] 4/8、BLOCK 判据 0/8 → 绿。反例 `n_l1_calibration_record.py` 6 例（误伤红/干净绿/过期红/缺记录红/换网格红/缺范围红）<1 s 全过；n_l1_thin_wall / single_bead / support_in_box_zone / core×4 复跑通过。

## 2026-09-13 —— Gate 数据对表 build #7（I3/I4/I5/I6 的 side_effects；I1 未实施故不做）

只改数据（features / fasteners / tolerances / parts / assembly 五个 YAML，文本级，注释未动），不动检查器、不动 duckstructure、不动 printability/slice_run。每个数要么 build #7 STL 射线/trimesh 实测（写 sha256 前 12 位），要么源码常量（指到 head.py/neck.py/legs.py 行）。
- features.yaml：N02-F05 nominal 15.0→15.05（neck.py:86+90，36 向 r 7.516..7.525，STL e283d7f6a23c），depth_kind blind_depth→cutter_length（下端开进原版顶盒空腔，L2 掏空 8.64≠刀长 9.265，pre-existing 红）；H01-F08 大通道 4.6→4.65（head.py:9+101，r 2.3222..2.325，STL 7f82bc3d1a7c），H01-F09 note 加右前脚 r<2.3 脚顶 233.2/厚 1.685；**H03-F02 重写**为 Ø1.7 自攻底孔（432 射线 r 0.849..0.850，孔1..3 盲深 7.0 刀底 224.5146，孔4 Ø1.7 段 5.0146 + 原版 Ø2.2 残段台阶通孔；placed STL sha 76781c1a566a…）；**H03-F04 删除**（z 231.0/231.3 r 1.4 四孔 12/12 向为料）；**新增 H03-F05 fill**（4×Ø3.6，head.py:15-17）与 **H03-F06 shell_clearance_cut**（DILATE6 0.1，head.py:26）；H03-F03 座 B 的 export_local 坐标由错误的『世界−(26,0,221.1146)』订正为 frames.per_part.H03 的 R/t（x_e=z_w−235.6146，z_e=−x_w+8.1），180 射线 r 11.0768..11.0913，L2 present/through 由红转绿；frames.per_part.H03.export_stl_bbox y ±45.8629 / z max 38.4843、H03 体积 23552.08（trimesh，watertight）；L02-F05 t 8.0→6.3 @y 37.15、export x 18.8→19.65、内面 y 34.0（两孔位）/34.65（两孔位落在头窝里）；catalog 171→172（counterbore 8→7、fill 9→10、shell_clearance_cut 2→3、H03 4→5）。
- fasteners.yaml：F22 pilot Ø1.7（measured）/深 7.0、joins『H03 底孔 Ø1.7 深 7.0』、engagement 6.3（derived，孔4 5.0）、stack 1.7（右前脚 1.685）、channel 4.65、status exported_unverified_on_print；F16 note 0.75→0.775；D-FAST-03 resolution 补一句。L5 抽查（H01,H03，scratch 输出）：F22 self_tap_radial_overlap +0.15 / engagement 6.3 / screw_length_rule 8≤8.4 / 坐面 [1.7,1.7,1.7,1.685] 全绿；engagement_per_hole 仍红：H01 右前脚 Ø2.7 孔在 build #7 网格上被孔底 4 个斜面片并进同一光滑片（max|N·ax| 0.316 > sin6°），detect_cylinders 不认圆柱 → 关联不上（射线 24/24 r 1.35 证明孔在），是检测器对该网格的局限，未改层。
- tolerances.yaml：pla_self_tap F22 unknown→satisfied（6.3，pilot H03-F02）；conflicts.pilot_hole_d 与 fits.pla.m2_pilot_hole_self_tap 加 H03 四脚 + head.py provenance。
- parts.yaml：H03 role/feature_count 4→5/mates_with『接缝已清零…原版×原版基线 67.9』（保留『接缝』+`top_head_shell` 让 l3 _seam_decl 仍走 original_seam_added）/deliberately_added evidence current 0.0。
- assembly.yaml：step 8 的 L_/R_hip_onto_roll_flange 两条 motion 加 note（I5 后预计峰值 0，待 L4 正式扫掠回填，未填 peak）。
- `gate.py --layers 2 --parts H03,H01,N02,L02 --skip-negatives`：本批声明全部 present/diameter/through/depth 绿；剩余红都是 pre-existing 或几何事实（fill 类埋在料里的 WARN、孔周壁 <2.5 的 WARN、H01-F08 通道是开口槽最多 21/24 向、N02/L02 horn_hole 2.2→2.4 retarget 未 build、H01-F05/F06 半座/前板孔的几何红、H01-F14 唇 B 与 H03-F03 同类错误帧『世界−(26,0,221.1146)』未改（09-12 ④ 范围，非本批））。
- **2026-09-13 独立复审（对表 build #7）**：逐条复现上批数据 —— H03-F02 432 射线 r 0.8490..0.8500、孔1..3 刀底 224.5146/孔4 轴心无料；H03-F04 288 点全为料；H03-F03 座 B 5 站 19/36 向 r 11.0768..11.0913、唇 44.3..44.8 r 9.30；N02-F05 三站 36/36 r 7.5160..7.5250、外壁 r 10.0；H01-F08 r_min 2.3222（x_e 15/20 站 31/36）；H01-F09 右前脚 r≤2.28 顶 233.2 / r≥2.35 顶 233.2146、其余三脚 1.70；L02-F05 内面 y 34.0/34.0/34.65/34.65（export x_e 16.5/17.15 互证）；H03 bbox/体积 trimesh 同值；frames R/t 用 placed/ 与导出件 bbox 互证（H03/L02/N02 三件 6 个角点全对上）；l3_static._seam_decl 对 parts.yaml H03 mates_with 仍匹配（key H03_original_seam，mechanical_audit current 0.0）；catalog 172 逐条核对；上批全部为字面替换（无 yaml.dump），HEAD 注释行未丢。复审只改三处：① features.yaml **H01-F14** 唇 B 帧订正（同 H03-F03：axis −z，pos (0.0004,0,−36.45)，span z_e −36.1..−36.8），加 verified_on_export（内圈 Ø18.58..18.60 上半周 17/36 向、外圈 Ø23.17..23.18 仅 6/36 向露出 —— 外圈并进 B 座上半圈的料里，L2 present 由 0/24 变 4/24 仍 WARN，几何事实）；② H01-F08 derived_from 旧行号『head.py:52-53,60』→ head.py:92/101；③ data/README.md 09-12 那句『H03-F04 扩口 / −0.1』加过时说明。L2 复跑（--layers 2 --parts H03,H01,N02,L02 --skip-negatives → scorecard.partial）：H03 3 红（F02/F03 wall WARN、F05 fill WARN）、H01 16、N02 20、L02 15，全部为 pre-existing / 几何事实 / retarget 未 build，本批声明无红。L5 抽查 F22 与上批一致。

## 2026-09-13 —— 审计第一批修复（检查器 + 反例包；数据 yaml 只动 waivers.yaml schema）

依据：`Gate独立审计_2026-09-13.md`（用户逐条核过采纳；口径修正 4 处：禁入体保持 128 边外接只改文本、支撑落点改解析 G-code、L6 目标区间只认 frozen 声明、标定 WARN 只报不判）。每条修复都带"修前红 / 修后绿"的反例。

### 内核 / 入口（core.py、gate.py、waivers.yaml:schema）
- F-核-1：`COVERAGE_ITEMS` 循环在清单为空或条目缺 id 时写 `L<层>/_coverage` FAIL(BLOCK)（以前 `if not want: continue` 静默跳过；assembly.yaml 19 步 0 步有 id，`L4/_coverage` 从未存在）。反例 n_core_coverage_no_id。**assembly.yaml 步 id 待数据侧补。**
- F-核-2：格级 inputs 隐含 `duckstructure/*.py`；L7 `_assign` 把实际读的 placed/*.stl 逐个 `res.inputs`，placed 指纹读不出改 unknown（以前 `continue`）。
- F-核-3：`gate.py --verify [scorecard.json]`：逐格 inputs_hash + source_manifest + git HEAD 与磁盘核对，不一致退出码 3。反例 n_core_verify。当前 out/scorecard.json 已被判作废（33 个输入变了、447 格过期）—— 符合预期，它是 build #6 的。
- F-核-4：豁免 id 必须带判据名（`L5/X:check` 或 `X.5.check`），只到格子的拒绝并记 waiver_notes；`waivers.yaml:schema.bound_input_hashes` 改成 {仓库相对路径: sha256}（旧文档的嵌套键永远匹配不上 manifest）。反例 n_core_waiver_cell_only、n_core_waiver（改用带判据名的 id）。
- F-核-5：新增状态 `RETIRED`（不阻断、不计 INCOMPLETE、单独计数）；l6_motion.py 三处、l7_mass.py 两处硬编码 STALE 改 RETIRED。反例 n_core_retired、n_l6l7_retired_not_stale。
- F-核-6：`--layers/--parts` 子集跑写 `scorecard.partial.{json,md}`（`partial: true`），不写 prev/impact；本轮跑过的层里范围外的格子按 inputs_hash 从 prev 继承（变了 → STALE）。反例 n_core_partial_inherit。实测 `--layers 0 --parts L01`：L01 重算、其余 17 件继承为 STALE（build #7 后 STL 已变）。
- F-核-7：`L0/_negatives` 格无论过不过都写，带 inputs_hash（反例缓存 key 覆盖的文件）。
- F-核-9：反例包结果按 `sha256(negatives/*.py + layers/*.py + core.py + gate.py + tool_access.py + slicing/slice_l1.py + data/*.yaml)` 缓存到 `out/negatives.cache.json`；key 计算 0.03 s；`--no-neg-cache` 强制重跑。
- 反例契约（F-反-1/3/4）：`runner.check_contract` 要求 `expect_severity` + `red`（每条 state==FAIL、severity==期望、measured 非 None，除非 `allow_unknown_red`）或 `assertions`（全 ok；两者都给时都校验）；空壳算失败。`_harness` 新增 `assert_red / assert_green / record / result`、`FakeCtx.mjcf()`；临时件目录改成每进程子目录 `_neg_tmp/p<pid>`（并行互删修复）。
- L6 N4：frozen 或上游 `range_deg` 不是有序 [lo,hi] → `_joints/range_declared_ordered:<关节>` unknown 并跳过该关节（反写时 check_angles 只给两端点 = 没扫）。反例 n_l6_reversed_range。

### 层（另见各层 docstring）
- L2 F-L2-1：`res.covered` 只登记至少发出一条带 measured 判据的特征；geom 无柱体也无 bbox/pos → `<fid>:geometry` unknown；`box_export_local {lo,hi}` 纳入 BBOX_KEYS。`_coverage` 由 171/171 → 160/171（9 条 sweep/cut 无探针 + L05-F09 + L06-F04），假绿转真红，**data 侧补 box_export_local 后恢复**。反例 n_l2_coverage_gap。
- L2 F-L2-2：`<fid>:diameter` 改棱边法（圆柱刻面纵向棱/端面弦上采样点到轴距离），对分段数免疫；比较吸收 1e-5 float32 表示噪声（阈值未动）。64 边 Ø14.85 由 14.834 假红 → 14.85。反例 n_l2_facet_diameter。
- L5 F-L5-3：配合桶 `fit_measured_geometry` 只在 relation_contact PASS 时 PASS；量了没过 → FAIL(BLOCK, measured=关系 id)。反例 n_l5_fit_measured_only_on_pass。
- L5 F-L5-1：l5_screwhead 跳过 kind=pilot_hole 接收孔（与 `_group_holes` 分类一致），detail 记跳过数；F24 的 −19.49 假红消失。反例 n_l5_head_on_pilot_hole。
- L5 F-L5-2：头侧只从 `fasteners.yaml:tool_access[].seats[].outward_export_local` 取（feature_id+map_index+hole_index 对孔）；取不到 → `head_side`/`seat_flatness` unknown，不取较差端。l5_function 坐面改按螺丝组穿件孔逐组判（subject=螺丝组），`seat_flatness`=头侧平面度+每向有料，新增 `seat_stack_spread`=叠厚极差；删除按直径扫全件的 `_screw_holes`。**没有 tool_access 的 28 组现在全 unknown（等坐面探针合并）。** 反例 n_l5_fg15（+远端台阶/未声明两例）。
- L1 F-L1-1/2/3：`_calibration/proven_parts` 范围内 BLOCK 判据 n_eval=0 或记录缺失 → unknown；新增 `warn_checks_over_limit` FAIL(WARN) 只报不判；calibrate_l1 把 PASS&evidence_n=0 计 unknown。`support_in_no_support_zone` 的"下界超"判红前要求本件 `support_model_brackets_slicer` PASS，否则 unknown（过渡保护；真实 G-code 支撑落点解析排第二批）。`l1_calibration.yaml` 已重跑（见文件头日期）：三条 BLOCK 判据 n_eval=0 → `L1/_calibration` 会是 unknown 红，直到标定件带切片记录。反例 n_l1_calibration_record（+3 例）、n_l1_support_in_bore/_box_zone（用层自报区间中点的切片桩通过过渡保护；桩不证明模型对，只让判据可检验）。
- L7 F-L7-2：`inertia_tensor_parsed` 改 n_I == body 数（以前"至少一个"）。反例 n_l7_inertia_tensor_all。
- 反例包（F-反-2/3）：六个只测辅助函数的改为经层 run；新增 n_l0_units_meters（N7；N8 Y-up 记为已知缺口）、n_l3_bearing_section（N2 + N1 空刀）、n_l6_reversed_range（N4）、n_l7_mass_torque（舵机 ×20 / 电池 −x 200 mm / forcerange ±0.7）。n_l1_support_in_bore 圆孔改方孔切（l1 支撑模型在 96 边圆孔上 shapely 420 s → 3 s，**l1 性能待查**）。README 事故表加文件名列；N5（螺丝加长 2 mm）、N6（删一个件）仍无专门反例。
- 未做（第二批）：F-L4-1 present 推导、F-L3-2/3、F-数-1 冻结项真核、F-L7-3/4/5/6、F-L6-1/2/3（目标区间只认 `frozen.yaml:joint_axes[].target_range_deg`）、F-L5-4/5、L3/L7 泛化、F-L3-1 文本 + keepouts.yaml facet_noise_mm3、G-code 支撑落点。

## 2026-09-13 —— 主线程：切片器常驻、build #7 基线、N03 数据、坐面探针

- 切片器：PrusaSlicer 2.9.6 dmg 重新下载（github prusa3d release，sha256 94fd7b8a…）装到 `/Applications/PrusaSlicer.app`；`slicing/slice_l1.py` 默认 `--exe` 指过去，`slice_run.slicer` 记出处。18 件按 build #7 重切（`docs/build_logs/slice_2026-09-13_build7.log`）贴进 `printability.yaml:slice_run`：rc 全 0，`layers_single_bead` 18 件全 0（L03 101 层只有外圈但 0 层单 bead，与 09-12 解析器修正一致）。
- N03（调查 I2 + 真切片附录，`docs/probes_2026-09-12/geometry_investigation/I2_N03_print_orientation.md`）：18 个朝向没有零侵入的，朝向不动；features.yaml N03-F05 `bore`→`clearance_cut`（让刀腔，无配合面）；N03-F07 `axial_span` 由 40 mm 刀长（把舵机腔圈进禁撑区）改为背板料厚并集 z_e 29.75..35.65（两排各 3.0，实测 y=7.5 排 29.75..32.74、y=−22.5 排 32.65..35.65），catalog bore 5→4 / clearance_cut 5→6。真 G-code 复核：`buildplate_only` 下 F02/F04/F05/F06 归零，F07 四背孔仍有支撑柱穿到床面（真几何，需逐特征 removable 豁免 + 装前 Ø2.4 通孔）。
- Gate 全跑基线（build #7 + 09-13 数据对表，审计第一批落地前的层代码）：979 s，85 PASS / 351 FAIL / 7 NOT_RUN / 1 RETIRED，BLOCKED（`docs/build_logs/gate_2026-09-13_build7_baseline.log`）。对 09-10：L3 38→26 红、L4 70→50、L1 切片类判据全绿；两个反例失败是审计批次改到一半的契约/标定反例，非件的问题。
- 真切片支撑落点分析（`docs/probes_2026-09-12/geometry_investigation/真切片支撑落点_2026-09-13.md`，分析表非判据）：auto 支撑下 H01 两轴承半座 + Ø22.78 座孔、L01 6704 座、N02 Ø15.05 通道、N03 Ø16.2 导向孔里都有真支撑；`buildplate_only` 只救 T01/L05/N03，H01/L01 轴承座救不了（待用户定：朝向/可拆桥顶/装前铰刀）。建议禁撑区分 `forbid` / `removable(post_process)` 两级。
- 坐面探针（`tools/gate/probe_seats.py --groups <一组>`，串行 24 组，`docs/build_logs/probe_seats_2026-09-13.log`，逐组输出 `out/probe/<gid>.{yaml,log,stdout}`）→ 合并进 fasteners.yaml 见下一条。
- 坐面探针合并（09-13 深夜）：24 组四轮跑完（探针修 3 个 bug：T_RANGE 15→45 粗细扫、`contains` 分块 200 防 5 GB 被杀、fine ts 先 round 再 unique），并入 fasteners.yaml → 25 组 `tool_access`、143 坐面、每组 `tool_access_probe_2026-09-13` 说明；F09 上排 hole0 两侧坐面按 0.05 步复量手工写入（`probe_note`）。F20 无坐面（曲壳，落差 0.19/0.63）、F05/F07 上排为垫管座只写说明。L4+L5 子集跑（F12 合并前）：`tool_reference` unknown 27→7；F06/F22/F03 转成有数的红（工位或头侧待核，见 docs/交接_2026-09-13.md §2c）。主线程数据修改到此为止。

## 2026-09-13 —— 审计第二批（主线程 + 子 agent A/L6/L7 + L1 agent；检查器 + 反例 + 数据字段）

依据 `docs/gate/Gate独立审计_2026-09-13.md` 与用户 09-13 第二批任务书（A 审计条目、B L5 对齐、C L1 真切片落点、D L4 数据复核、E 缓存 key）。每条修复都带"修前红 / 修后绿"反例；阈值一个没改、判据一条没删。全量跑与归档见本节末。

### L4 / 装配数据（F-L4-1、D14、D15；主线程）
- F-L4-1：`l4_assembly.py` 新增 `intro_table / derive_present / installed_upto / judge_present`：每个动作与每个 `tool_states` 工位判 `present_covers_derived`（BLOCK：present ⊇ movers ∪ 早于本位置、所属子总成 ∈ closure 的实体，按左/右/中央侧过滤）与 `present_only_installed`（WARN：present 里出现按 seq 还没装 / 没有任何一步装的实体；同步稍后动作的只记 detail）。子总成闭包读 `assembly.yaml:subassemblies`，归属读每步 `subassembly_of`（motions 可逐动作覆盖），顺序读 `seq`。缺声明 → unknown。反例 `n_l4_present_derived.py`（漏写已装件红 measured=1 / 补上绿 / 顺序矛盾 WARN / 缺子总成 unknown）。
- `_Names._lookup` 轴承按 `components.yaml` 型号/三元组解析外径（`_bearing_od`），不再写死 6700→15/6704→27；`6702×2`、`22×16×4` 现在能落到 placed 实体（以前 unresolved）。型号代码只认 model 开头（D-COMP-01 那句"错标成 6704ZZ"不登记）。
- `assembly.yaml`：每步加 `id`（step01…19，L4/_coverage 用）、`seq`（物理顺序 1,2,3,4,5,7,9,10,6,8,11,12,13,18,14,15,16,17,19）、`subassembly_of`；顶层 `subassemblies`（ankle_arm/ankle/upper_leg/leg/trunk/body/head/neck/neck_head/robot）；`already_installed` 按 seq 重算；`tool_states.*` 加 `after_step`/`after_motion`/`side`/`subassembly_of`。文本级替换，注释未动。
- D15 F22：`tool_states.head_shells_on` 去掉 `orig_top_head_shell`（探针：4/4 头只被顶壳挡 22–39 mm；去掉后刀路 0 mm³、4/4 可见）→ 物理顺序先拧 F22 再盖顶壳，`after_motion: H03_bottom_shell`。
- D15 F06：步 8 重排 —— 新增 `L/R_hip_onto_pitch_flange`（L02 在腿台面贴俯仰法兰，subassembly leg，沿俯仰轴抽出），`L/R_hip_onto_roll_flange` movers 改为 L02+整条腿、len 60→100（60 mm 证不出脱离），删 `*_upper_sub_onto_hip`；`hippitch_flange_*` 工位改腿台面（12/12 可见、0 mm³），`hiproll_flange_*` present 加腿（F04 带腿复算 3.3e-6 mm³、12/12 可见）。步 8 十条动作本机扫掠全绿。
- D15 F03：结论"真拧不到（直杆）"—— 内排两颗从坐面沿 −x 13.86 mm 撞 T01 电池仓前壁（厚 3.5，Ø4 批杆 44 mm³）；不改数据不改件，三条处置路线见 `docs/gate/L4数据复核_2026-09-13.md` §3。
- D14 复核：36 动作 / 24 工位 present 全部 ⊇ 推导集合；`orig_face_part`/`orig_jaw` 没有任何装配步（步 17 present 里出现 → WARN）；步 6 右"左腿已完整"的假设在 step 粒度下表达不了（WARN 记录）。全文 `docs/gate/L4数据复核_2026-09-13.md`。

### L3 / 内核 / 冻结项（主线程）
- F-L3-2：`l3_static._ko_geoms` KO01 不再 `import conn_cut`：走廊 (c) 由 `keepouts.yaml:KO01.geom_verbatim(c)` 的截面与 y 区间 + `dims.socket_center_mm` 建盒，窗口 (a) 由 `dims.conn_x_mm/conn_z_mm` 在 y=±y0 面上按 `window_face_grid_mm`（0.5）取点、离面 `window_face_probe_offset_mm`（0.01），点落在打印件实体内 = 面上有料 → `keepout_KO01_window_face` FAIL(BLOCK)（口袋壁隔 0.3 盖住窗口边缘环带不算）；舵机局部→世界只借 `duckstructure.lib.sfw`（落位）。CAD `conn_cut` 只作对照 `keepout_KO01_vs_cad_cutter` INFO（独立−CAD / CAD−独立 体积）。dims/网格缺 → `keepout_dims_declared` unknown 且不留 0 对的 PASS。真数据：`keepout_intersection` 5.9e-05 与基线同、窗口面 14×234 点全空。反例 n_l3_ko01_independent（声明走廊加长到 20、料放 y=25 → CAD 切刀看不见、独立实体 64 mm³ 红；贴面的口袋壁红 / 隔 0.3 绿；dims 缺 unknown）。
- F-L3-3：`components.yaml:components[].envelope_solid`（ring: bore/od/t；box: size_mm + overall_mm + exact；none + why；box 三边按 overall_mm 与 OBB 三轴长度配对，两个 overall 值差 <0.5 分不出轴 → unknown 不猜 —— 舵机 T19.9/W20 差 0.1 配错轴曾在全量跑里造出 H02 垫柱 × 薄段 1.36 mm³ 假红，用 overall 25.7 = 厚段 22.8 + 法兰 2.9 分辨后归零）→ `_envelope_solid` 独立建实体，落位只借 placed 的 OBB（`trimesh.bounds.oriented_bounds`），尺寸不抄 CAD/placed；`placed_covers_envelope`（顶点法：OBB 三边 / 环的顶点内外径 vs 声明 ±`envelope_vs_placed_mm`，box 非 exact 时 ⊇）+ `part_vs_component_envelope` / 件格 `component_envelope_<id>`（BLOCK）；原 `part_vs_component_solid` criterion 写明"实体 = build 导出的 placed 占位体，与 CAD 同源"。7 条元件补 `envelope_solid`（servo 34×20×19.9 薄段 ⊇、4 种轴承环、电池 72×25×18 exact、original_prints none）。真数据全部 PASS（servo 225 对、6704 100 对…峰值 0）。反例 n_l3_component_envelope（占位体挖 3×3×3 缺口 + 载体筋坐在缺口里：同源判据 0 绿、独立实体 8 mm³ 红；不声明 → unknown）。
- §2.6（L3）：元件认领改读 `components.yaml:claim`（与 L7 同一份：mjcf_servo_geom 名单来自 MJCF body.servos `servo__<body>_<drives>`、envelope_ring/box、placed_prefix），不按 category；KO06 `servo_frame_of_joint`、KO07 `axis_joint`、KO11 `probe_zone_z_mm`（盒 x/y 外沿取 placed 包围盒）、KO12 `exempt[]`（part+segment+why）、KO15 `fov_deg/apex_world_mm/optical_axis_world` 全部读数据，缺 → 一条 unknown（`*_declared`）；`_DEFERRED` 表删除 → `keepouts.yaml:KOxx.checked_in_layer`（KO02/03/04→4，KO10/13→6）+ `covered_by_subjects`（KO02: 9 步含舵机滑入；KO03: step01–04；KO04: disasm03–05），`core.obligations` 按它派义务、`core.build_scorecard` 汇总成 `L{层}/KOxx`（`covered_by_cells`：缺格 NOT_RUN、状态取最差、evidence 求和）；件格 `keepout_*` / `component_*` 的 evidence_n 改为查过的对数（以前是超阈值对数）。反例 n_l3_keepout_data_driven、n_core_keepout_layer_routing。
- F-数-1：`l3_static._frozen_checks`：`frozen.yaml:battery_bay_26.measured_on{bay: T01, door: B01}` → 仓中心射线量 BX1/BAY_FW/BZ0/BAT_Y/RAIL_Y、导轨带射线量 RAIL_Z0/BZ1、SHELL_BOSS 四柱有料、门板 DOOR_T/BX0/DOOR_YLO、底脚 FOOT_Z/FOOT_X[1]/FOOT_Y（FOOT_X[0] 与门板连成一体不单独核）、SNAP 卡珠面与导轨面差 ≤0.1 射线分不出 → unknown；`h01_sbc_posts.measured_on: H01` + `post_axis_world` → 柱外沿内 3 mm 截面闭环：count 4 / hole_pitch [58.08, 23.02] / post_d 5.0 / pilot_d 1.7 全 PASS；`imu_pose.measured_on: T01` + `mount_hole_d_mm 1.7` → ±y 射线扇找到孔心 y ±8.0 均值 0 PASS、生成 MJCF `<site imu>` 与 frozen pos_local_m 偏差 0 PASS、delta 算术 PASS；9 个非几何项（BAT_CLR / 死常量 / SERVO_SHIFT / P / 3 个函数体）登记 INFO"由 build 的 verify_frozen 锁定"。阈值 `tolerances.yaml:frozen_dimension_mm ±0.1（src: assumed）`、`envelope_vs_placed_mm ±0.1（src: assumed）` 新增。反例 n_l3_frozen_items（仓半宽错 0.5 / 柱距错 1 / IMU 孔偏 1 红，对照 14 条绿，measured_on 缺 unknown）。
- L3 子集跑（`--layers 3 --skip-negatives`）：92 条/37 红 → 135 条/40 红；新增红 = SNAP unknown（射线分不出）+ 新 unknown 只在无 claim 的 14 类未建模元件（原本就是 world_placement unknown）；`servo_s288` 14/14、轴承 9/9、电池 1/1 认领；`original_prints instance_count 3≠4` 与基线同。

### L1 支撑落点（L1 agent + 主线程收尾）
- C-10：`slicing/slice_l1.py` 解析 `;TYPE:Support material` / `Support material interface` 挤出段（G1 带 E 且 XY 位移；类型跟层），按 `criteria.support_landing_sample_step_mm`（0.2，含端点）采样，z = 层顶 `;Z:`，经 `orient_transform`（align_vectors M + shift）逆变换回 export_local，对 `l1_printable.no_support_zone_set`（层与脚本共用，`zones_sha256`）逐区数点 → `slice_run.parts.<件>.support_landing{per_zone, hits_forbid_samples, hits_removable_samples, support_path_mm…}`。`l1_printable.support_in_no_support_zone`（forbid 级，BLOCK）/ 新 `support_in_removable_zone`（WARN + 逐特征后处理文本）/ `support_model_zone_crosscheck`（模型上下界 vs 真落点，INFO）；没有记录 / source_sha256 或 zones_sha256 对不上 → unknown。
- C-11：`printability.yaml:no_support_zones.tiers`（forbid: bearing_bore/journal/spot_face + 走廊 `mating_shells_export_local` 壳层；removable: 其余 7 类，含 slide_corridor 口袋盒，各带 post_process），`from_features_yaml_kinds` 必须 = 两级并集；`per_feature_overrides`：N03-F07（removable，装前 Ø2.4 通四背孔）、N03-F02（Ø16.2 导向孔顶清孔）、**H01-F06**（主线程 09-13：留 removable —— head.py:44 实测前立板承压圈 r 6.8，这个 Ø22.78 孔不是 B 盘/轴承入口，只是拆 N04 的 Ø6 顶杆通道，无配合面；`features.yaml:H01-F06.purpose` 同步订正并留 purpose_note；手算表 §3.1 把它归 bearing_bore 是按旧 purpose）。
- C-12：`printability.yaml:parts.N03.slicer_args: [--support-material-buildplate-only]` → argv 追加，记入 `slicer_argv_extra`。
- C-13：`features.yaml:L01-F13 / L03-F05` 加 `geom.mating_shells_export_local[]`（配合面 0.5 mm 壳层，forbid），口袋盒本体降 removable。
- 主线程收尾：`slice_l1.py` 的 WORLD_DOWN / PLACED_NAME 表与 `if pid == "N02"` 分支全部搬进 `printability.yaml:parts.<件>`（`down_world` / `fill_density_percent` / `perimeter_generator` / `slicer_args`；缺 → 退出码 4 不给缺省；placed 名取 parts.yaml `placed_instances[0]`）；`--parts` 子集重切沿用其余件记录；`no_support_zone_set` 的 sha 只带**本件**特征的 override（原来带全局 override，改一条 override 会让 18 件记录全部作废）。18 件全部重切（`slice_run.date 2026-09-13`，18/18 source_sha256 与 zones_sha256 对上）：forbid 落点只剩 H01 145.4k（F05 两半座）、L01 46.8k（F10 + F13 壳层）、L03 8.3k（F05 壳层 + F06）、H02 2.4k（F07 锪平），其余 removable WARN。逐件对照手算表 `docs/gate/支撑落点对照_2026-09-13.md`。反例 n_l1_support_landing_tiers（forbid 红 / removable WARN 带后处理 / 声明变了没重切 unknown）、n_l1_support_in_bore / _box_zone 改为落点桩（`_harness.landing_stub`）。
- E-16：`gate.py` 反例缓存 key = 静态文件全集（`tools/gate/**/*.py`、`duckstructure/*.py`、`tools/cad/*.py`、`data/*.yaml`、`slicing/*.yaml`、`l1_calibration.yaml`、标定网格）+ 运行时 `sys.modules` 仓库内模块清单 + trimesh/manifold3d/numpy/shapely/Python 版本；命中时 `L0/_negatives` 照写并标 `cached`。反例 n_core_neg_cache_key。

### L5（agent A）：L5 头判据起点改坐面 + 阈值来源 + 盲深字段（检查器 + 反例；数据只补 `tolerances.yaml` 阈值 `src` 与 `data/README.md` 一句）

依据：主线程 09-13 对齐问题（25 组 `tool_access` 143 坐面并入后，14 组 `head_seat` unknown "孔落在导出包围盒外"、F01/F06 "声明头侧与实测孔轴不共线"、F02/F03/F10 "6/12 孔头侧未声明或左右冲突"）。真因：`l5_screwhead` / `l5_function` 第 2 段拿 `feature_hole_map` 的孔点当射线起点，而它是**刀心**（切刀中点，常离件 15–19 mm 甚至在件外）；`declared_head_sides` 的键没有 `instance`；同一颗螺丝的沉孔条目被当成另外 6 颗。每条修复都带"修前红 / 修后绿"的反例（先写反例、在旧代码上跑出失败，再改层）。

### 层（l5_screwhead.py / l5_function.py）
- F-L5-2 第二半（起点）：头判据按 `tool_access[].seats[]` **逐坐面**判，起点 = `point_export_local`、头侧 = `outward_export_local`；`feature_hole_map` 孔点只当**轴线锚**（坐面点到孔轴横向偏差 > 1e-6 → `head_seat` unknown，与 `tool_access.py` 同规则）。孔轴优先取特征声明轴（`geom.instances[k]` 按 `feature_hole_map[].instance` 取，`hole_geom()`），实测轴起点改到孔腔里（坐面点沿 −outward 进 0.5×孔径），`hole_axis_declared_vs_measured` 保留为旁证。射线只认坐面外侧 ≤ 头高（`frozen.yaml:P_dict.m<N>_head.h`）内的第一张进料面（`_seat_end`，按面法向分进/出），头高区外的杯壁/另一堵墙不算坐面；该孔叠厚由同一批射线（足印内圈）的"进料面→下一张出料面"给，删掉 `_first_run`。足印环带在坐面头侧 1e-3 mm 处全是料 → 坐面点在料里 → unknown（不报成"头悬空"）。逐孔判据名改 `head_seat_flatness:hole<map_index>.<hole_index>`。反例 n_l5_seat_origin_cutter_mid（刀心在件外 20 mm：修前 `head_seat` unknown → 修后 `head_seat_exists`/`head_seat_flatness`/`seat_flatness` PASS；坐面挖 0.5 台阶 → `head_seat_flatness` FAIL(BLOCK) 0.5；坐面横向偏 0.3 → unknown）、n_l5_fg15 新增 E（坐面点写在料里 → `head_seat` unknown）。
- F-L5-2 第二半（键）：`declared_head_sides` → {(feature_id, **instance**, map_index, hole_index): outward}，冲突只在同一 instance 同一孔方向不一致时成立；新 `seat_table()` 把左右实例（mirror_y，同一份 STL、export_local 同坐标）同 outward 的坐面合成一行，几何量一次、detail 记"坐面覆盖 instance [...]"，evidence 不重复计；某 instance 缺坐面 = 那颗螺丝未声明。头侧判据只覆盖 `head_locator_map_indices` 指向的 map 项（沉孔/铣面条目不进"未声明"，也不作为叠厚/坐面测量孔）；locators 缺/重复/越界 → `head_side` unknown；任一头侧孔取不到坐面 → 该组 `head_seat`/`head_side` unknown，不用部分孔冒充全组；没有 `tool_access` 的组保持 unknown。`l5_function` 第 2 段同口径（`_group_holes` 带实例几何、rows 限 locator 条目、坐面点必须在孔轴上）。反例 n_l5_seat_instance_key（L/R 同向 → 绿且探孔数 2 不是 4；同 instance 反向 → `head_side` unknown；右实例缺一坐面 → unknown 点名 instance）。
- F-L5-4（阈值来源）：新 `threshold_meta()/src_label()/AssumedThresholds`：`fits.*.target_range_*`、`feature_check_tolerances.{seat_flatness_spread_mm,horn_clock_deg,horn_concentricity_mm,hole_depth_mm}` 读取时把 "阈值 src=…" 写进 criterion；节点无 `src` → 引用它的判据 unknown（"阈值没有来源"：`fit_value` / `relation_contact` / `seat_flatness` / `seat_stack_spread` / `horn*:clock_index` / `pattern_radius` / `head_seat_flatness` / `stack_from_seat_crosscheck` / `counterbore_diameter`）；`src=assumed` → 照判 + 每 (subject, 键) 一条 `threshold_assumed:<键>` FAIL(WARN)，measured=阈值本身（fits 桶挂在桶格上，feature_check 阈值挂 `L5/_thresholds`；两个模块各发自己的一条，同键会出现两条）。**未纳入**：`engagement_by_joint_type.*.range_mm`、`screw_length_rule.tip_margin_mm`、`hole_diameter_mm`（L5 只当关联容差）。`fit_on_placeholder` 保持 WARN。反例 n_l5_threshold_src（assumed → WARN 且 measured 非空；删 src → `fit_value`/`head_seat_flatness` unknown；measured → 无 WARN）。
- F-L5-5（盲深）：`_blind_depth` 先读 `fasteners.yaml:<组>.pilot.pilot_depth_mm`（`core.num`），detail 写 `pilot.pilot_depth_mm（src=…）`；取不到再退回 joins/location 正则；两者都有且不一致 → `screw_length_rule` unknown 并把两个数写进 detail。反例 n_l5_pilot_depth_priority（pilot 3.0 → 8 > 4.0+3.0−0.3 红；joins 4.5 → 绿；3.0 vs 4.5 → unknown；4.5/4.5 → 绿）。
- 子集跑（`--parts`）范围外的穿件孔不再报 "N 个声明孔一个都没关联到 []" 的 `engagement_per_hole` unknown（F19/F20/F21/F24 在 L01,L02,H01,H03 子集里）；全被跳过就不发。

### 数据
- `tolerances.yaml`：32 处阈值节点补 `src: "assumed"` + `src_note: "2026-09-13 补 src：区间由本文件提出，无试件/手册来源"`（29 个 `fits.*.target_range_mm/deg`；`feature_check_tolerances.hole_depth_mm/horn_concentricity_mm/horn_clock_deg` 注明"由 tools/gate/README.md 第 2 节提出、本文件转录"；`fits.battery_bay` 注明冻结采用值 BAT_CLR）。**不补**：`fits.axis.concentricity.target_range_mm`（区间引用 `datum_vs_mjcf_mm`，自己没 src → 引用它的判据 unknown）、`fits.tpu.process`（区间 null）。已有 src 的（`seat_flatness_spread_mm`）不动。这是如实记录，不是编数。
- `data/README.md` 字段约定加一句：`hole_positions_mm` 是刀心，L2 用 `axial_span_mm` 兜住，其它层不许当坐面/起点，头/坐面一律用 `tool_access[].seats[]`。

### 子集跑 `--layers 5 --parts L01,L02,H01,H03 --skip-negatives`（改前 343 条/221 红 → 改后 383 条/247 红；多出的红基本是 31 条 `threshold_assumed` WARN）
- F02：`head_side` unknown（"6/12 未声明"）消失；`head_seat_exists 0/6` / `head_seat_flatness 0.0` / `stack 5.35` 不变，detail 记覆盖 yaw2roll + yaw2roll_R。
- F03：`head_seat`（包围盒外）/`head_side` 两条 unknown → 有数：`head_seat_exists 0/2` PASS、`head_seat_flatness 0.0` PASS、`counterbore_diameter 4.4` PASS；**新红** `stack_from_seat_crosscheck` FAIL 2.99（记录 3.29，差 0.30；独立射线复核 L01_yaw2roll.stl (8±1.366, y, 5) 沿 +y：进料 −13.24 → 出料 −10.25 = 2.99，与 L01-F09 purpose "余 3.0" 一致；3.29 来自 09-09 final_measurements，疑为旧 build）。数据未改。
- F06：`head_side`（"与实测孔轴不共线"）unknown → `head_seat_exists 0/6` / `head_seat_flatness 0.0` / `stack 7.5` PASS（声明轴 −x 按 `geom.instances[1]` 取）。
- F22：全部不变（`seat_flatness 0.0`、`head_seat_exists 0/4`、`stack 1.685`、`engagement_per_hole` 仍红）。
- F01 未在子集内；T01 探针：seat0 (−16.5,25.5,27.65) 头侧 +1e-3 环带 0/72 在料、内侧 72/72 在料，−z 穿越 27.65 进 / 24.65 出 → 坐面点在料面上、叠厚 3.0，坐面数据可用（点与刀心重合是巧合，不是复制错误）。
- 反例：10 个 `n_l5_*` 全过（含 4 个新建 + fg15 加 E），单个 0.75–4.55 s。

### L6（agent L6）：F-L6-1 / F-L6-2 / F-L6-3（审计 `docs/gate/Gate独立审计_2026-09-13.md` §L6）

### `frozen.yaml`（只动 `joint_axes[]`，文本级插入，注释未丢；`yaml.safe_load` 通过）
- **15 条 `joint_axes[]` 各新增 `target_range_deg`**（`frozen.yaml:26-29` 起，每条紧跟 `range_deg` 之后）：
  14 条 MJCF joint 写 `{v: [lo, hi], src: "<上游 robot_walk.xml 路径:行 <joint name range=弧度原值>（弧度→度，保留 1 位小数）", src_note}`，
  值全部 = 上游 `upstream/microduck_rl/src/mjlab_microduck/robot/microduck/robot_walk.xml` 的 `<joint range>`
  （**没有**用生成的 `sim/duck_s288/robot_walk_s288.xml`）；现在没有人为收窄，所以没有 `date`/`reason`。
  `mouth`（`exists_as_mjcf_joint: false`）写 `v: null` + `unknown_class: not_applicable` + `unknown_reason`。
- `range_deg` 与其余字段一个没动；`counts.joint_axes` 仍是 15。

### `tools/gate/layers/l6_motion.py`
- **F-L6-3 目标区间**
  - `l6_motion.py:82-83` 新常量 `_TARGET_KEY` / `_TGT_TOL=0.1°`；`:359` `_target_range()`：只读 `frozen.yaml:joint_axes[].target_range_deg`，
    缺 / 不是 [lo,hi] / 非数 / lo≥hi / 超出上游扫描域 / 人为收窄（与上游差 >0.1°）无 `date`+`reason` → 不可用；`:507,533` 在关节清单循环里分成 `tgt` / `tgt_bad`。
  - `:649` `in_target(pose)`（非零关节全在各自目标区间内；含不可用关节 → None）、`:687` `sev_of()`（区间内有一条 → BLOCK，全在区间外 → WARN，分不出 → None=unknown）、`:695` `ws_note()`（"工作空间问题（控制端限位），不是件的问题"）。
  - `:448` `crit` 改写为新口径（含"目标区间只认 frozen.yaml 声明"）；`:773-806` `single_axis_sweep`：目标区间不可用的关节不扫、判 unknown（detail 写缺 target_range_deg），其余按 `sev_of` 定 BLOCK/WARN；
    `:834-845` `pair_combination` 父关节不在清单 / 任一关节目标区间不可用 → unknown；`:888` 严重级按两轴都在区间内判。
  - `:949` `min_clearance`、`:982-988` `collision_buckets`、`:1482-1486` `motion_collision`、`:1531-1545` `keepout_motion`、`:1129` `combo_collision_inside_free_range` 同口径（含 None → unknown）。
  - `:1014-1120` **`collision_free_range` 改判**：解析生成的 `sim/duck_s288/robot_walk_s288.xml`（`:385` `_mjcf_joint_ranges_deg`），每条 `<joint range>` ⊆ 本轮无碰撞区间否则 FAIL(BLOCK)（`:1106`）；
    新增 `gen_range_covers_target`（`:1113`）：⊇ `target_range_deg` 否则 FAIL(WARN)。生成文件缺 / 解析不了 / 有关节未扫 → 两条都 unknown。"需要收窄"只写进 detail，不再是 BLOCK 理由。
  - `:84` `_RANGES_OUT` 常量取代写死的导出路径（反例改指临时文件，不再覆盖真 `out/mjcf_ranges.json`）；导出 JSON 多了 `target_range_deg` / `unscanned_no_target_range` 两键。
- **F-L6-1 网格**：`:80` `_COMBO_STEP_DEG = 5.0` 取代 `_COARSE_DEG = 10`（原 `max(10°, 量程/12)`）；`:847-848` 两轴统一 5° `check_angles` 网格；
  `:831` criterion 写明步长；detail 记 `5.0° 统一网格 A×B 个姿态（+ 峰值粗格附近 2.5° 加密 N 个姿态）`。真场景逐对实测：组合扫描 44 s → 351 s（`head_pitch+head_yaw` 5.5 s → 86 s 最重）。
- **F-L6-2 豁免**：`:219` `mating_pairs` → `zero_gap_pairs`（只是几何事实，不再是豁免依据）；`:398` `_contact_pairs()` 从 `relations.yaml:*.contact.parties` 解析件对
  （`placed` 认单只实体、`part` 认该件号全部实例，经 `parts.yaml` 桥接的 `stem2pid`）；`:701` `stem2pid` 前移到零位姿基线之前；
  `:732-760` 新判据 `_zero/declared_contact_pairs`（解析不到的声明 FAIL(WARN)）与 `_zero/undeclared_zero_gap_pair`（零位间隙 < 阈值但没声明的对，FAIL(WARN) 列出，不阻断）；
  `evaluate()` 的 `mating` 参数改为只收声明对（`:185`）。
- `:1572` `res.evidence` 新增 `records_in_target_range / records_outside_target_range / records_target_unknown / joints_without_target_range / combo_grid_step_deg / declared_contact_pairs / undeclared_zero_gap_pairs`。

### `tools/gate/negatives/`
- 新增 `_l6_scene.py`（不以 n_ 开头，runner 不收）：替身 placed/ + 真运动树 + 可注入合成 evaluate / 只留几只实体 / 只扫几条关节 / 临时生成 MJCF / 猴子补丁 `PLACED _Scene _GEN_MJCF _RANGES_OUT` 并还原。
- 新增 5 个反例（都先在改代码前跑出 passed=False，再改到 True）：`n_l6_combo_pocket.py`（F-L6-1）、`n_l6_target_range_severity.py` / `n_l6_target_range_declared.py` / `n_l6_gen_range_vs_free.py`（F-L6-3）、`n_l6_undeclared_zero_gap.py`（F-L6-2，真几何真布尔）。
- 既有 `n_l6_reversed_range` / `n_l6_scene_inventory` / `n_l6l7_retired_not_stale` 改完仍过；8 个 L6 反例都 < 5 s、`runner.check_contract` 全 None。
- 主线程核对 L6 子集跑（`--layers 6 --skip-negatives`，460 s）：与 out/scorecard.json 相比 `collision_free_range` BLOCK 1→0（生成 MJCF 6 条收窄 range 全部 ⊆ 本轮无碰撞区间）、新增 `gen_range_covers_target` WARN 1（训练域被收窄）、`undeclared_zero_gap_pair` WARN 1；其余 BLOCK 数不变 —— **因为 target_range_deg 现在全部 = 上游区间**，扫描域内的碰撞都在目标区间内。要把"工作空间问题"转 WARN，需要人在 `frozen.yaml:joint_axes[].target_range_deg` 里带 date+reason 收窄，Gate 不代做。

### L7（agent L7）：F-L7-3/4/5/6 + §2.6 L7 泛化（检查器 + 反例 + 数据只加字段/删 yaml 自述要删的键）

依据 `docs/gate/Gate独立审计_2026-09-13.md` §"L7 质量与力"与 §2.6。每条先写反例、在旧层上跑出失败（scratchpad `neg_l7_before/`：反写区间 `static_torque` PASS evidence_n=2；删电池质量 `com_in_support_home` 仍 PASS 13.353；无 `component_qty`/`component_body`/`torque_source_consistent` 判据；6 对声明被 `== 5` 判红），再改层，再跑到全过。

### 层（tools/gate/layers/l7_mass.py）
- F-L7-3 `static_torque`（l7_mass.py:1156-1245）：`range_deg` lo ≥ hi 或 `check_angles` 评估点数 < 3 → 该关节 `static_torque` unknown（以前反写只给两端点、evidence_n=2 也 PASS）；criterion 写明"评估点数 ≥ 3（check_angles 2.5° 零度对齐网格 + 两端，lo<hi 且宽度 ≥ 2.5° 时必然 ≥ 3；== 2 就是退化）"。新增 `joint:<j>:static_torque_home`（l7_mass.py:1224-1245）：全部关节同时置 frozen home_rad，同阈值（额定 × margin，margin null 时按必要条件 1）单独判 PASS/FAIL，measured=占额定比。`_head_budget` 同样跳过区间无效的关节并判 unknown（l7_mass.py:1712-1750）。反例 n_l7_static_torque_home_and_range（反写 left_knee → unknown；head_pitch home 取反 + 头偏航舵机实体沿 +y 平移 1.5 m + 舵机 ×4 → head_yaw 扫描 0 绿、home 1.2155 红；对照 14+14 全绿）。
- F-L7-4 质量清单缺口联动：`_mass_items` 第 5 个返回值 `gaps`（l7_mass.py:573-833；缺口 = qty>0 无质量 / 无 claim / 认领数≠qty / 定不出 body / 有质量认领不到实体 / qty 非整数 / 密度无来源）+ run 里未归属的打印件（l7_mass.py:896）。gaps 非空 → `static_torque` / `static_torque_home`（l7_mass.py:1214-1233）、`com_in_support_zero|home`（l7_mass.py:1623-1628）、`head_mass_budget`（l7_mass.py:1759-1763）一律 unknown，detail = "质量清单不全 → unknown，不给下界当绿。仅含已知质量的**下界**：…" + `_gap_text(gaps)`（l7_mass.py:1271）；`worst_joint_torque_ratio` / `total_mass_vs_mjcf` / 单脚余量 INFO 注明是下界。真数据现有 32 项缺口 → 这些判据现在全部 unknown（**这是要的结果**，见下"子集跑"）。反例 n_l7_mass_gap_unknown。
- F-L7-5 额定扭矩唯一来源：`_rated_torque_Nm`（l7_mass.py:137-149）只读 `tolerances.yaml:load.servo_rated_torque_Nm.stall_torque_Nm`（yaml 自述 authoritative），删掉镜像键优先读取与 docs/ 散文 grep 退回路径（连带删掉只在退回路径上才会发的 `rated_torque_not_in_tolerances`）。新 `_torque_source`（l7_mass.py:151-197，run 最前面）：`_load:rated_stall_torque` INFO PASS(measured=权威值) / 取不到 → unknown；`_load:torque_source_consistent`：废弃键仍在且 ≠ 权威 → FAIL(BLOCK, measured=差值)，相等 → PASS(INFO) 提示应删，不存在 → PASS(INFO)。反例 n_l7_torque_source（写回 0.5 → −0.1 红；真数据 / 写回 0.6 绿）。
- F-L7-6 元件认领泛化：`_CLAIM_BY` + `_mass_items` 按 `components.yaml:components[].claim` 认领（l7_mass.py:553-569 注释、704-748 `claim_stems`），**不再按 category 分支**。没有 claim → `component_body:<id>` unknown（l7_mass.py:763）；规则用不了 → `component_claim_rule` unknown（773）；`component_qty`：认领实例数 == qty → PASS(INFO)，≠ → FAIL(BLOCK, measured=实例数)（779）；qty 不是整数 → `component_qty` unknown（744）；qty=0 → 不装、不要求质量（components.yaml speaker/filament 的 gate_schema_note 要的就是这个）。宿主 body 改为"housed_by 全部实例的 body，去掉左右镜像后仍不止一个连杆 → 不猜；否则每个实体按最近 body 原点落到左/右"（l7_mass.py:663-682；以前只取第一个实例的 body，右腿件会挂到左 body）。`_layer:component_claims` INFO 簿记（831）。反例 n_l7_component_claim。
- §2.6 泛化：`mirror_body_pairs`（l7_mass.py:438-459）由 frozen left_/right_ 同名对推（left_ 数 == right_ 数 == 配到的对数，双方 body 都在 MJCF 里），criterion 写"配到的对数 == 数据声明的对数"；`_home_pose`（l7_mass.py:1279）：任一关节缺 home_rad → `_load:home_pose_declared` unknown、home=None → `static_torque_home` / `com_in_support_home` unknown（以前 `or 0.0`）；`_stability`（l7_mass.py:1533-1664）落地件只认 `parts.yaml:ground_contact: true`，没有声明 → `support_polygon` unknown；筋容差从 `tolerances.yaml:load.min_section_and_rib.rib_declared_vs_measured_tol_mm` 读（l7_mass.py:1830-1850，缺/无 src → `_section:rib_declared_tol` unknown 且每条 rib_thickness/rib_length unknown）；密度（603）/ 稳定裕度（1585）/ 筋容差（1847）src=assumed → `threshold_assumed:<键>` FAIL(WARN, measured=阈值)，src 无 → 引用它的判据 unknown；`part_mass` / `com_in_support_*` / `rib_*` / `static_torque*` 的 criterion 都带 src 标签。**数值一个都没改**（1.27 / 3.0 / 0.1 / 0.6）。反例 n_l7_generalized。
- 模块 docstring 加 2026-09-13 一节。

### 数据（只加字段；唯一删除是 yaml 自述要删的镜像键）
- `components.yaml`：顶部注释（:10-15）说明新字段 `claim`；给现有 7 条元件补 `claim`（servo_s288:37 `by: mjcf_servo_geom, body_from: mjcf_servo_host`；bearing_6704zz:134 / 6700zz:177 / 6702zz:217 / 22x16x4:254 `by: envelope_ring`；battery_3s:286 `by: envelope_box`；original_prints:774 `by: placed_prefix, pattern: orig_, body_from: mjcf_part_mesh, mass_estimate_from_geometry: true`）—— 规则内容 = 原层代码四个分支逐条搬入，没有新匹配。**字段说明**：`claim.by ∈ {mjcf_servo_geom（placed/servo__<body>_<drives>，来自 MJCF body.servos）, envelope_box（envelope_mm.v 的 a×b×c 反算体积+包围盒 ±0.05 / 1%）, envelope_ring（内径×外径×厚反算环体积+包围盒）, placed_prefix（placed 名前缀 claim.pattern）}`；`claim.body_from ∈ {housed_by（缺省）, mjcf_servo_host, mjcf_part_mesh}`；`claim.mass_estimate_from_geometry: true` = mass_g 取不出数时按体积×密度推 INFO 值（不冒充声明，仍算缺口）。其余 14 条（主板/IMU/摄像头/屏/麦/小板/降压/总线板/插头/线/开关/绑带/耗材/喇叭）**没有 claim**：placed/ 里没有它们的实体，层现在对它们发 `component_body` unknown（speaker qty=0 除外）。未删任何字段。
- `tolerances.yaml`：删 `load.servo_output_bearing.rated_stall_torque_Nm`（:1142 处留注释说明；它自己的 duplication_note 写明应删）；`load.servo_rated_torque_Nm.mirrored_into`（:1422）改为"已删除"；新增 `load.min_section_and_rib.rib_declared_vs_measured_tol_mm: {v: 0.1, src: assumed, src_note, applies_to}`（:1181-1186，从 l7_mass.py 的 ±0.1 逐字搬入）。
- `parts.yaml`：L06 加 `ground_contact: true`（:215，值来自本条 material "TPU 95A" + role "TPU 鞋底"，逐字搬入）。
- 未动：README / CHANGELOG / negatives/README / data/README.md / frozen.yaml / bench.yaml（bench.yaml:248 那句"层现在读的是它的镜像 load.servo_output_bearing.rated_stall_torque_Nm"已过时，待数据侧改）。

### 反例（tools/gate/negatives/）
- 新增 `_l7_fixture.py`（共用夹具，不是 n_*）：`complete_inventory` 把真数据补成质量清单完整的对照 —— **只删不编**：无实体无质量的 14 类元件 qty=0；6702 / 22x16x4 / original_prints qty=0 并从替身 placed/ 拿掉实体；6704 / 6700 housed_by 收成单一宿主件。真数据下 F-L7-4 让整机判据全 unknown，对照必须用它。
- 新增 n_l7_static_torque_home_and_range（17 s）、n_l7_mass_gap_unknown（17 s）、n_l7_component_claim（17 s）、n_l7_torque_source（1.7 s，快跑：parts 清单置空）、n_l7_generalized（17 s）。修前 5/5 失败、修后 5/5 过，均通过 runner.check_contract。
- `n_l7_mass_torque.py` 改用夹具（对照 / ①③ / ② 三次 run 都过 `complete_inventory` + `placed_stand_in`），仍过（24.6 s）；n_l7_inertia_tensor_all / n_l6l7_retired_not_stale / n_core_severity 复跑通过。

### 子集跑 `gate.py --layers 7 --skip-negatives`（scratchpad gate_L7，9.97 s）：L7 310 条 / 135 红（基线 build #7）→ **348 条 / 179 红**
- +14 `joint:*:static_torque` unknown、+14 `static_torque_home` unknown、+1 `com_in_support_home` unknown、+1 `head_mass_budget` unknown、`com_in_support_zero` 由 WARN-FAIL(0.843) 变 unknown(WARN)：全部因质量清单 32 项缺口（4 种轴承跨 body / 无质量、13 类电子件无实体无质量、original_prints 无标量质量且 qty 4≠3、connector_xt30 qty "2 对"）—— **预期结果，不填数**。detail 里保留下界（neck_pitch 扫描峰值 26.1%、home 4.5%；home 重心余量 12.811 mm；头部预算上界 509.2 g）。
- +12 `component_body` unknown（sbc/imu/camera/display/mic/sensor_small_boards/buck/bus_adapter/cable/switch/strap/filament：没有 claim，以前静默消失）；−2 `world_placement_for_mass`（sbc / connector_xt30 改由 component_body / component_qty 表达）；−1 `component_mass`（speaker qty=0 不再要质量）。
- +1 `original_prints:component_qty` FAIL(BLOCK, measured=3)：qty 4 但 placed 只有 3 个 orig_*（components.yaml 自己写了 jaw_soft 没有独立实体）—— 真的数据/CAD 不一致，红得对；+1 `connector_xt30:component_qty` unknown（qty "2 对" 不是整数）。
- +3 `threshold_assumed:*` WARN（density 1.27 / static_stability_margin 3.0 / rib 容差 0.1，measured=阈值）。
- 新绿：`_load:rated_stall_torque` 0.6、`_load:torque_source_consistent`（废弃键已删）、`_load:home_pose_declared` 14、`_mjcf:mirror_body_pairs` 5（== 声明 5 对）、6 条 `component_qty` PASS（servo 14 / 6704 4 / 6700 2 / 6702 2 / 22x16x4 1 / battery 1）。
- 其余类别（load_criteria 18、inertia_criteria 15、torque_criteria 14、forcerange 14、load_path_* 33、rib_* 3、density_per_material、static_torque_margin…）与基线一致。

### 数据变更汇总（第二批，全部文本级编辑、注释未丢、`yaml.safe_load` 通过）
- `assembly.yaml`：步 id/seq/subassembly_of、`subassemblies`、`tool_states.*.after_step/after_motion/side/subassembly_of`、步 8 重排（D15）。
- `keepouts.yaml`：KO01 `window_face_grid_mm/window_face_probe_offset_mm`、KO02/03/04/10/13 `checked_in_layer(+covered_by_subjects)`、KO06 `servo_frame_of_joint`、KO07 `axis_joint`、KO11 `probe_zone_z_mm`、KO12 `exempt[]`、KO15 `fov_deg/apex_world_mm/optical_axis_world`、KO06/07/09 `facet_noise_mm3`。
- `components.yaml`：`claim`（7 条，L7 agent）、`envelope_solid`（7 条）。
- `frozen.yaml`：`joint_axes[].target_range_deg`（15 条，L6 agent）、`battery_bay_26.measured_on`、`h01_sbc_posts.measured_on/post_axis_world`、`imu_pose.measured_on/mount_hole_d_mm`。
- `tolerances.yaml`：32 处 `src: assumed`（A）、`frozen_dimension_mm`、`envelope_vs_placed_mm`、`load.min_section_and_rib.rib_declared_vs_measured_tol_mm`（L7）、删 `load.servo_output_bearing.rated_stall_torque_Nm`（yaml 自述要删）。
- `parts.yaml`：L06 `ground_contact: true`。`printability.yaml`：`no_support_zones.tiers/per_feature_overrides`、`parts.<件>` 逐件切片配置、`slice_run` 重生成。`features.yaml`：L01-F13/L03-F05 `mating_shells_export_local`、H01-F06 purpose 订正。`data/README.md`：刀心不是坐面一句（A）+ 本批字段说明。

### 全量跑（第二批后，`docs/build_logs/gate_2026-09-13_第二批后.log`；归档 `tools/gate/out/archive/scorecard_2026-09-13_第二批后.json`）
- 64 个反例全过（缓存 key 变了重跑，≈217 s）；总 ≈1010 s。基线 85 PASS / 351 FAIL / 7 NOT_RUN / 1 RETIRED → **107 / 357 / 6 / 1**，仍 BLOCKED。
- 逐层（判据数/红）：L0 96/14 → 98/14；L1 184/53 → 219/58（+removable WARN 15、forbid 真红 4：H01/L01/L03/H02）；L2 558/247 → 560/248；L3 92/37 → 134/38（envelope/frozen 实测全绿、SNAP unknown、14 类未建模元件 unknown 照旧）；L4 148/54 → 362/67（present_covers_derived 141 条 + 5 WARN + KO02/03/04 汇总格）；L5 533/315 → 545/296（坐面起点改 seats 后 head_seat unknown 转有数，+31 threshold_assumed WARN）；L6 73/56 → 78/58（collision_free_range 绿、gen_range_covers_target/undeclared_zero_gap_pair WARN；BLOCK 不降因 target = 上游）；L7 310/135 → 348/179（质量缺口 → 整机判据 unknown、component_body unknown 16、original_prints qty 4≠3）。

## 2026-09-13 —— 任务 A：S288 舵机参数全部改手册值（CAD 源码 + 检查脚本；**Gate 数据一个字没动、发布目录未同步、Gate 未跑**）

依据：手册尺寸图 p2（`docs/reference/s288/S288使用手册_含尺寸图_2026-09-10.pdf`，主线程 400 dpi 读数）+ 用户 2026-09-13 拍板"我自己量的不准，所有参数按手册"；分度圆 09-13 实物定案 Ø10.5（旧 r4.75 摆臂扣法兰只对得上 1 孔）。
产物：`cad/duck_s288/*.stl` + `placed/` + 两份 audit json = **build #8**（`docs/build_logs/build_2026-09-13_manual_dims.log`：静态 0、mechanical_audit PASS、EXIT=2 = B01 未闭环预期；扫掠 268 条与 build #7 同集合，全在 MJCF 极限角、旧检查域内 0）；
三只读检查 + 自证 `docs/build_logs/checks_2026-09-13_manual_dims.log`（idlercheck 锁死 0 / asmcheck 14 颗全可抽、-y 走廊两条同 build #7 / audit_screws 问题数 6 同 build #7 / 6 孔拟合 12 组全 r=5.250、口袋 10.30/13.30、法兰让位 ≥Ø14.6）。
**冻结项没动**：电池仓 B01 常量、关节轴线（kin）、壳柱 SHELL_BOSS、香橙派立柱；测试台 `tools/cad/testbench.py` 只改常量与注释，**未重跑**（`cad/testbench_s288/` 仍是 09-13 白天的 STL）。

### `duckstructure/s288.py`（参数字典 S，全部标"手册尺寸图 p2（2026-09-13 用户拍板：自量不准，全按手册）"，旧实测值留作历史）
| 行 | 键 | 旧 → 新 | 来源 |
|---|---|---|---|
| 16 | `T` | 19.9 → **20.0** | 手册 p2 轴心段厚 |
| 17 | `T_lo` | 22.8 → **23.0** | 手册 p2 接线端厚 |
| 18 | `step_z` | (-7.0, -12.0) → **(-7.0, -13.5)** | 手册 p2 像素读数：厚段自接线端 ≈10.8（z≈-13.7）、斜坡 ≈6.4、薄段自 z≈-7.3；取 -13.5 比 -13.7 保守 0.2 |
| 22 | `flange_d` / `flange_h` | 13.9 / 2.9 → **14.0 / 3.0** | 手册 p2 法兰 Ø14 高 3 |
| 23 | `horn_r` | 4.75 → **5.25** | 手册 Ø10.50 + 09-13 实物定案；⛔ 争议块（旧 20–26 行）删除，换成 3 行定案说明（24–26 行）指向 `docs/reports/分度圆Ø9.5还是Ø10.5_2026-09-12.md` |
| 28 | `rear_boss_d` / `rear_boss_h` | 13.8 / 2.9 → **14.0 / 3.0** | 手册 p2 副轴 Ø14 高 3；端面 -13.0 与厚段背面 -13.0 齐平（20+3=23） |
| 2–6 | 模块 docstring | "标 [量] 的值来自手册图纸像素反推或纯假设" → 本体/法兰/副轴/分度圆全按手册，[量] 只剩插座/插头 | |
| 149 | 新增 `x_env_boss_face()` | = `x_idler_face()−1.0` = -14.0（servo_envelope 副轴让位外端面；c 在公式里抵消） | 供 lib 推 X_ENV_BOSS |
| 143–150 | 站位注释 | 12.85/-9.95/-12.85/-14.95 → 13.0/-10.0/-13.0/-15.0，标旧值 | |
| 102–109 | `servo_envelope` docstring | 说明包络仍按保守台阶 (2,-1)，不因手册有了 step_z 放松 | |
不动：W/L/top/horn_hole_d/horn_center_d/idler_*/mnt_*/horn_depth/mnt_depth/conn_*/plug_*/clr/wall/plate_t/stub_*/brg_*/mass_g（19.5 g 官方参数表）。

### 由此推出的站位变化（全部由 S 推导，不再写死）
法兰面 12.85→**13.0**；薄段背 -9.95→**-10.0**；厚段背/惰轮端面 -12.85→**-13.0**；载体背板内面 XR -13.15→**-13.3**；让位体副轴面 -13.85→**-14.0**；等厚背板外表面（薄/厚）-13.25/-16.15→**-13.3/-16.3**；躯干顶板 BZR0/BZR1 144.65/147.65→**144.8/147.8**；甲板 DECK_TOP/BOT 121.25/119.15→**121.2/119.0**（手册尺寸下前板底正好 = 原版甲板底 119.0，不再削 0.15）；N03 A 盘坐面 YRM_A2 11.2→**11.35**；N02 顶盘底 224.2646→**224.115**。

### `duckstructure/lib.py`
- L16 `XR` 注释 -13.15→-13.3；**L17 新增 `X_ENV_BOSS`**（-14.0）；**L18–20 新增 `x_bshell_out(t, thick)`**（等厚背板外表面 -13.3 / -16.3，沉孔坐面从它推）。
- L33–37 `ANK_X0/ANK_X1b/ANK_X1`：写死 -17.4/-21.4/-21.6 → 从 X_ENV_BOSS 推（-14.0−3.0−0.4 = **-17.4，手册尺寸下与旧值相同**）+ 断言 ==-17.4/-21.4（`tools/cad/ankle_split.py` 分体站位按这两个数写死，ANK_X0 再变要一起改）。
- L150–151 `BZR0/BZR1`：写死 144.65/147.65 → `pt(sfw("trunk_base",0), XR)[2]` = **144.8** / +PLT = **147.8**（定义移到 `pt()` 之后）。电池仓 BZ1=146.9 不动。
- L234 `CARD_T`：3.1 → `(-T/2 − XR) − 0.1` = **3.2**（垫片卡缝 3.3；目前无载体用 card 模式）。
- L346 `bearing_driven_clearance`：环中心写死 14.875 → `xf + 2.025`（x 12.8..17.25）。
- **L475–484 `back_shell`：新增 `BSHELL_EPS=1e-3`**，板内腔按 `servo_envelope(grow−1e-3)` 做、调用方再减 servo_env(grow) 定最终内腔面。原因：手册尺寸下让位体副轴面落在 -14.0 这种站位后 L04（原版板 + 背板 + 让位刀共面/共柱面）manifold 输出经 float32 焊合仍剩 1 条非流形边 + 1 片 -0 体积碎片，`checks.export` 的 L04 严格断言不过（首次 build 失败，见日志开头被覆盖前的记录：本节"过程"）；退 0.001 后 L04 退化 0 / 非流形 0。外表面只薄 0.001。
- L430 `flange_relief` 默认 c：0.2 → **CLR=0.3**（Ø14.4→**Ø14.6**，题面"法兰让位孔 ≥ 14+2·clr"；影响 L01/L02/L04/L05/N02 的法兰让位圈）。
- L566 `mnt_cut2` 新增断言 `cb_x0 is None or cb_d > 0`（本任务第 3 次 build 时三处 cb_d 相减写反成负值、沉孔被静默跳过，audit_screws 才暴露 L04 下排叠厚 4.70；已改正并加断言防复发）。
- 注释更新（旧数→新数或标"旧值"）：SLIDE_CLR、ANK 注释、P.brg_yaw 注释、carrier docstring/站位注释、mount_cut_local、原版重雕段注释、driven_patch、idler_hub/idler_bore/idler_keep、flange_slot、seat_ring_clearance/zone。

### `duckstructure/neck.py`
- L16 `NK_LIP_Y`：写死 (10.25, 12.35) → `(T/2+CLR, x_flange_face()−0.5)` = **(10.3, 12.5)**。
- **L20 `NK_IDLER_BORE` 15.0 → 16.0**（报告 §定案后 b）；L21–30 注释按 r 8.0 重算：垫柱余量 0.466（报告 0.47）、Ø4.4 沉窝层韧带 0.766（报告 0.77）、Ø2.4 孔层 1.766 —— **建完 STL 射线实测 0.767 / 通孔 r 7.990..8.000**（checks 日志 [自证补充]）。
- **L105 `NP_IDL_HUB_D` 14.0 → 15.0**（报告 §定案后 a；`lib.idler_hub` 断言：孔外缘 6.55 → 毂边 0.95 ≥ 0.8；Ø14 时 0.45 会响，已验证会响）。
- L147–150：`YRM_A2` 写死 11.2 → `法兰面世界 x(8.1) + YRM_A_STACK(3.25)` = **11.35**；`YRM_BORE` 起点跟随；`YRM_A0` 6.4 不动。F17 叠厚保持 3.25（audit_screws jaw_soft 法兰孔 3.25 ✓）。
- L191 ringA 让位孔：`flange_d+0.3`（Ø14.3）→ `flange_d+2·CLR`（**Ø14.6**）。
- L224 N03 上排沉孔：`cb_d=6.75`（沉到 -13.25）→ `x_bshell_out(PLT) − (−20)` = **6.7**（沉到背板外表面 -13.3，叠厚仍 3.3）。
- 注释：NP_CB_D（5.25+Ø4.4 → Ø15.0）、Ø15.05 通道对螺丝头 0.275、N02 叠厚 3.40（旧 3.55；M2×6 咬 2.6）、起子通道 14.7、A 端法兰面 8.1 = 原版 XL330 接口面 8.10、N04 注释 227.6、xr0 -13.3。

### `duckstructure/trunk.py`
- L60–63 `DECK_TOP/DECK_BOT`：写死 121.25/119.15 → 从髋偏航舵机帧推 **121.2 / 119.0**（前板底 = 法兰面 118.5 + 0.5；L01 毂顶 118.5 → 间隙 0.50 不变）。`CLR` 加进 import。
- **L164 `SHR_IDL` 毂径 14.0 → 15.0**（报告 §定案后 a；皮层填孔盘 sd 14.6 保留，理由写在注释）；mechanical_audit T03 惰轮毂 306.8/307.3 mm³（旧 243.3/243.7）。
- 注释：法兰 Ø14/118.5/121.5、座环 z 114.5..119.0、背板 144.8..147.8、y0..y1 13.0..16.0、SLIDE_CLR=0.4（13.4；旧注释错写 0.2/13.05）、壳内壁 -17.1、惰轮螺丝 5.40/咬 2.6、N01 Ø16。

### `duckstructure/legs.py`
- L9–10 新增 `L01_SEAT=19.2`（原版杯壁外表面 = 横滚舵机顶端 112.0+CLR，不随 T 变）/ `L01_STACK=5.35`；L28 沉窝深 `1.0` → `L01_SEAT − (xf+5.35)` = **0.85**（叠厚保持 5.35，M2×8 咬 2.65；mechanical_audit 6×16 全 5.35）。
- L30 L01 上排沉孔 `cb_d=1.25` → `x_bshell_out(3.0) − (−14.5)` = **1.2**（沉到 -13.3，叠厚 3.3）。
- L41 挡肩薄片补切 wbox x1 写死 18.8 → `pt(Rs, xf−0.1)[0]+0.05` = **18.95**（座孔起点随 xf 外移 0.15，薄片 0.15→0.3，不补切会剩 0.1）。
- L91–92 / L103 垫管座：`x_in=-13.0, x_out=-14.95` / Ø5.5 让位 -14.95 → `x_in = x_bshell_out(3.0)+0.3`（-13.0）、`TUBE_OUT = -T/2−5.0`（**-15.0**）。叠厚 5.5 不变。
- **L125 新增填柱**：原版 L04 踝轴心的 XL330 阶梯定位孔（Ø5.5 台阶面 x=-14.0 / Ø2.7）用 Ø6 填掉（它整个落在背板副轴盘 + Ø9.95 轴颈里；台阶面与 X_ENV_BOSS=-14.0 严格共面是 L04 退化的诱因之一）。
- L130 L04 下排沉孔 `cb_d=1.55` → `x_bshell_out(3.0,thick=True) − (−17.7)` = **1.4**（沉到 -16.3，叠厚 3.3；audit_screws ankle 背角孔 4 孔 3.30 ✓）。
- L134–135 踝轴颈起点写死 -13.85 → `X_ENV_BOSS−1.0` = **-15.0**（退进副轴盘 1.0，真·体积重叠；起点 = -14.0 时端面与盘面差 2e-15 留退化）。
- L162 L05 沉窝起点写死 19.55 → `xe`（= 法兰面+6.7 = **19.7**；不改会留 0.14 封闭空腔）；叠厚 5.5 不变。
- L23 `flange_relief` 调用不变（默认 c 变 0.3）。docstring 数字更新。

### `duckstructure/head.py`
- **L27–31 新增 `H01_FOOT_RIM_R = horn_r+2.1+0.05 = 7.4`；L97–99 右前脚 (49.1, 9.35) 承压圈内侧削到离横滚轴 r≥7.4**（报告 §定案后 c：A 端 6 颗 Ø4.2×45 起子刀路 0° 那条擦到承压圈 1.19 mm³）。刀沿横滚轴长 8（首版写 2.1 只盖住脚盘中间一段，mechanical_audit N03 tool corridors 仍 FAIL 0.19 mm³，第 2 次 build 才过）。实测：脚盘剩 42.7 mm³、圈内缘 r 7.391、孔边到削面 1.15；6 条刀路对 H01 全 0。
- L112–113 新增 `H02_POST_L/H02_PLATE_T/H02_CB = 3.2/3.0/0.6`、`H02_ARM_X=(-18.15,-12.0)`；L121–130 H02 压板/垫柱/头窝全部从舵机薄段背面世界 x（-14.9）往 −x 推：压板 -18.05..-21.05 → **-18.1..-21.1**，垫柱 3.25 → 3.2+0.05 压进板，头窝 -20.76 中心 → 板外面沉 0.6。叠厚 5.60 / 臂 6.10 不变（mechanical_audit 2×16 全 5.60 / 6.10）。
- 注释：法兰面 8.1 / 薄段背 -14.9 / 厚段背 -17.9；前立板 Ø22.78 孔说明 r 7.4 / Ø>14.8。

### `tools/cad/*.py`（检查脚本）
- `assembly_audit.py:45–53`：轴承 -x 面 12.85 ×6 → `XF = D.S['T']/2 + D.S['flange_h']`（13.0）；踝 6700 -21.4 ×2 → `D.ANK_X1b`。
- `mechanical_audit.py`：L01 叠厚 5.35 → `D.L01_STACK`；N02 期望 3.55 → `NP_CHK_OUT − NP_CB − xf` = 3.40；H02 期望 5.60 → `H02_POST_L+H02_PLATE_T−H02_CB`；H02 臂 6.1 → 由 `H02_ARM_X` 推；N03 起子刀起点 `xf+3.25` → `YRM_A2 − 舵机心 x`；T03 毂探针中心 -14.5 → `x_idler_face()−1.5`；horn_r 处已读 `S['horn_r']`（确认，只改注释"09-13 定案"）。
- `idlercheck.py:56–66`：外圈取样半径 `rear_boss_d/2−0.8`（5.25 时 6.2 落进孔带 3.95..6.55）→ `(rear_boss_d/2 + horn_r + idler_hole_d/2)/2` = **6.775** + 断言在孔带外 ≥0.1、盘内 ≥0.1；docstring "争议" → "定案"。
- `testbench.py:136–138`：`HORN_R_ARM = 5.25` 写死 → `S["horn_r"]` + 断言 ==5.25；文件头/注释站位数更新（12.35→12.4、-12.85→-13.0、-15.95→-16.1、14.85→15.0、17.35→17.5、副轴 Ø14×3）；**未重跑，STL 未变**（文件头已写明重跑会变什么）。
- `asmcheck.py:49`、`coupons.py:9/72–73`：注释（Ø15.8→Ø16、r4.75→S、-12.85/-9.95→-13.0/-10.0）。
- `V2_S288版发布产物/06_CAD源码/audit_screws.py`：未改（全部读 S）。

### 过程（5 次 build，每次 ≈8 min）
1. L04 export 断言"退化面/非流形共边"失败 → 定位到 -14.0 站位共面（见 back_shell / L04 填柱 / 轴颈起点三条）。
2. mechanical_audit FAIL `N03 tool corridors` 0.19 mm³（H01 承压圈刀长写短）。
3. 通过，但 audit_screws 暴露 L04 下排叠厚 4.70（三处 cb_d 符号写反、沉孔被静默跳过）。
4. 通过；自证发现法兰让位 Ø14.4/Ø14.3 < 14+2·clr → 放到 Ø14.6。
5. **最终**：静态 0、PASS、三检查 + 自证全过。日志文件是第 5 次的。

### 螺丝叠厚变化（audit_screws，对 build #7；其余各组不变）
F12b 颈俯仰惰轮 5.55→**5.40**（M2×8 咬 2.6）；F11 N01 上排 5.20→**5.30**（M2×8 咬 2.7）；F14/F14b N02 两侧 3.55→**3.40**（M2×6 咬 2.6）；壳柱"背角孔 shell_L/R"伪配合行 3.47/3.70→3.42/3.65（同 build #7 的 audit 噪声）。F02 5.35 / F03 3.3 / F09 3.3 / F10 5.5 / F15 3.3 / F17 3.25 / F18 5.6 / F04/F06/F08 7.5 / F16 3.5 不变。

### Gate 数据后续要跟（本任务未做）
`features.yaml` 8 条 `horn_hole.pitch_r_mm 4.75`→5.25（`tools/gate/retarget_horn_r.py --old 4.75 --new 5.25 --apply`）、所有 12.85/-12.85/-9.95/-13.15/144.65/121.25/119.15 站位、N01-F?? 通孔 Ø15→16、T03/N02 毂 Ø14→15、F12b/F11/F14/F14b 叠厚、`frozen.yaml` 若记了顶板 z、`fasteners.yaml:tool_access` 坐面 y/z（法兰面外移 0.15）。发布目录 `V2_S288版发布产物/` 仍是 build #6。

## 2026-09-14 —— 复审修复 r1（对手册尺寸 build #8 的 2 BLOCKER + 6 MAJOR；MINOR/NOTE 未动）
build：`docs/build_logs/build_2026-09-13_manual_dims_r1.log`（第 3 次 r1 build = 最终，EXIT=2 = B01 预期）；三只读检查 + 8 条复量：`docs/build_logs/checks_2026-09-13_manual_dims_r1.log`。
复量脚本 `measure_r1.py` 正文附在 checks 日志末尾（量法 = 复审同款：manifold 布尔 / min_gap / 射线）。

### 逐条：修前 → 修后（复量数字）
| # | 发现 | 改动（file:line，旧 → 新） | 修前 | 修后 |
|---|---|---|---|---|
| B1 | L01 F02 12 颗头压进髋横滚舵机顶端 | `duckstructure/legs.py:14` `L01_STACK` 5.35 → **4.0**；`:15` 新增 `L01_SCREW_L=6.0`；`:33` 沉窝深 = 19.2−(13.0+4.0) = 2.2（旧 0.85）。F02 M2×8 → **M2×6**（咬 2.0；8 > 4.0+3.0−0.3 会顶底） | 坐面 18.35，头 z 111.55..113.15 vs 舵机顶 112.0：∩ 5.646 mm³/颗 ×12，min_gap 0 | 坐面 17.0（16 向 ×6 孔 ×2 侧全 4.00），头 z 112.9..114.5：∩ 0 ×12，min_gap **0.9**；头∩L01 0；头↔6702 内圈 0.25（同一转动体、内圈端面 17.0 与坐面共面，无相对运动，记录不判） |
| B2 | T02 左壳压住 T01 轭 F12 6 颗头 + 孔内"销" | `duckstructure/trunk.py:209–215` 左壳新增 6×Ø(4.0+2·CLR)=Ø4.6 沿 +y 从轭盘外表面 16.0 下 0.5 打穿（头 + PH0 通道，同 T03 F12b 做法）+ 中心 Ø5 只切到轭外 SHELL_CLR（不在壳外开洞）；`:66` 新增 `YOKE_Z0=144.0`（`:114` 原刀里的写死 144.0 改用它） | 头∩shell_L [10.66,16.01,16.01,10.66,16.01,16.01] mm³；Ø2 螺杆∩ 0.645..0.835/孔；孔 1/2/4/5 孔心射线壳料 y 15.6..17.9；起子 Ø4.2 ∩ 3.0..4.1；+y 退 0..40 峰值 16.007 | 全部 **0**（头/螺杆/起子/滑入）；孔心射线 6 孔全空；Ø26 足印 y 16.0..16.5 内壳料 27.35 → 6.45 mm³ **全部在 z<144.0**（x 19..27，轭带下方躯干本来无料的壳壁，不是销；z ≥ 144.05 内 = 0） |
| M3 | H01 右前脚承压圈孔壁到削面 1.02 | `duckstructure/head.py:34` `H01_FOOT_RIM_R`（整圈 r≥7.4）删 → `H01_FOOT_TOOL_D = 4.2+2·KO_OVER = 4.3`；`:103–106` 脚盘只减 6 条起子刀路本身（沿 x，位置从 Rr/horn_r 推，与 mechanical_audit 同源；只有 60° 那条碰脚） | −y 壁厚 z 231.55/231.9/232.36/232.8/233.1/233.17 = 1.815/1.606/1.360/1.154/1.047/1.022；脚盘剩 42.70 mm³ | 1.849/1.602/1.397/1.312/1.308/1.311，72 方位最薄 **1.308**（mechanical_audit 6 高度 ×72 方位 1.310@z232.84,270°）；6 条 Ø4.2×45 刀路 ∩ H01 全 0，脚盘到刀路 0.0499（=KO_OVER）；脚盘剩 43.24 mm³ |
| M4/M8 | H02 压板内面离头横滚惰轮端面 0.2 | `duckstructure/head.py:121` `H02_POST_L` 3.2 → **3.4**（叠厚 5.6 → 5.8，F18 M2×8 咬 2.2）；`H02_ARM_X` 不动（臂坐面铣到 −18.1，臂叠厚 6.1 不变） | min_gap(H02, 惰轮 Ø14×3) 0.200；探针 +0.3 ∩ 2.836 mm³；端面 188 采样点沿 −x 命中 0.200 | **0.400** / 0 / 188 点全 0.400；mechanical_audit H02_stack 2×16 全 5.80、臂 6.10 |
| M5/M6 | T02 左壳与左髋偏航惰轮盘实体相交 0.019 mm³（<0.05 阈值盲区） | `duckstructure/trunk.py:200–202` 两侧壳各减同侧髋偏航舵机 Ø(14+2·CLR+0.2)=Ø14.8 × (薄段背 −10.0 → 惰轮面 −13.0−CLR) 让位柱；`:170` `HIP_IDLER_RELIEF_EXTRA=0.2`（64 边内接刀 Ø14.6 平边 7.291 实测 0.291 <0.3，第 1 次 r1 build 发现） | shell_L∩舵机 0.01859 mm³（全在副轴），Ø14.2×3.1 探针 ∩ 0.2197，min_gap 0.0，柱面 21600 点 203 个在壳内；shell_R 0.3385 | shell_L ∩ 0 / 探针 0 / min_gap **0.300**（轴向 = CLR）/ 0 点；shell_R **0.391** |
| M7 | 头横滚舵机厚段底角离冻结上头壳 0.199 | `duckstructure/lib.py:137` `SERVO_SHIFT[("jaw_soft",1)]` −1.5 → **−1.7**（沿自身轴 +0.2，世界 x 心 −4.9 → −4.7、法兰面 8.1 → 8.3；复审 fix_hint 写的 −1.4 方向反了，且 +0.1 只到 0.265——最近点斜向，每 0.1 涨 0.066）。跟着帧走：`neck.py:149` YRM_A2 11.35 → 11.55、H02 站位（压板仍 −18.1..−21.1）、H01/H03 舵机让位刀、KO01 CF4 窗。**连带**：`neck.py:221` N03 加 `flange_relief(Rr)`（原版 A 端腹板从 8.10 起，法兰面 8.3 后有 0.2 层压进 Ø14：零位 17.67 mm³、head_roll ±25° 20 姿态，第 1 次 r1 build 发现）；`head.py:150–153/167` H03 加 `minkowski_box(H02, ±CLR)` 让位刀（舵机 +0.2 后 H02 下垫柱底落到原版地板垫台立壁旁，min_gap(H02,H03) 0.244 → 0.069，第 2 次 r1 build 发现；修后 0.300） | min_gap(舵机, 上头壳) 0.1993；body_prism(c=0.2/0.25/0.3) ∩ 0.0027/0.0113/0.0294 mm³ | **0.3313**；c=0.2/0.25/0.3 ∩ 0.0000/0.0008/0.0056（0.3 下 0.0056 mm³ 是斜向底角，min_gap 已 ≥0.3）；× H03 0.300；F17 叠厚 3.25 不变；head_roll_B 轴向隙 bearing_to_N03 0.12 / N04_to_N02 0.60 不变 |

### 检查脚本
- `tools/cad/mechanical_audit.py`：`:55` L01 咬入 `8−v` → `D.L01_SCREW_L−v`；`:58–66` 新增头 vs 髋横滚舵机（∩≤0.05 且 min_gap ≥0.3）；`:76` 新增 `_review_r1()`（H02↔惰轮 / 两壳↔髋偏航惰轮 / 舵机↔上头壳 / F12 头×T02 静态+滑入+起子+销 / H01 脚 4 最薄壁 ≥1.2）挂在 `out['review_r1']`；H03 拆卸路径 hosts 加 `head_clamp`；新增 `H03 vs H02 nominal clearance ≥0.3`；汇总行 `[09-14 复审不变量]`。
- `tools/cad/idlercheck.py:68` 取样圈加盘边 r=rear_boss_d/2=7.0（复审建议）。副作用：踝的 L07 后臂在 r 6.775/7.0 两圈上各 12 点命中 → 现在显示为"从动件 ankle_rear_arm 差+8.40"（6700 轴承在中间，结论不变 ○）。
- `tools/cad/assembly_audit.py:57` 注释 −4.9/−1.5 → −4.7/−1.7（代码本来按帧推）。

### Gate 数据（本次只改了三处值，其余列为待跟）
- `fasteners.yaml` F02：`spec` M2×8 → **M2×6**（保留 `spec_was_until_2026-09-14`），`stack_mm.v` 5.35 → 4.0，`engagement_mm.v` 2.65 → 2.0；F18：`stack_mm.v` 5.6 → 5.8，`engagement_mm.v` 2.4 → 2.2（src_note 各带日期）。`counts.by_spec` 直方图（采购清单原文）未动。
- `frozen.yaml:619` SERVO_SHIFT `jaw_soft_1` −1.5 → −1.7（src_note 写明理由；`joint_axes_rule` 允许沿轴平移）。
- 待跟（未做）：`features.yaml` T02 新增 6×Ø4.6 通孔特征 + 两壳惰轮让位、L01 沉窝 0.85→2.2、H02 垫柱 3.4、H03 新增 H02 让位；`features.yaml:995`/`keepouts.yaml:KO01 CF4`（头横滚舵机 +0.2）；`fasteners.yaml` F02/F17/F18 `tool_access` 坐面坐标（F02 坐面 18.35→17.0、F17 坐面 11.35→11.55）；`assembly.yaml` T02 装配序备注（F12 头露在轭外、壳上 6 孔对头）。

### 未做 / 观察
- 复审 MINOR/NOTE 未动。
- L01 导出 STL 仍 退化面 34 / 非流形边 30（洞边 0，与 build #8 相同，不是本次引入；只有 L04 有严格断言）。
- 扫掠 268 个相交对/姿态、旧检查域内 0，与 build #8 同集合（全在 MJCF 极限角）。

## 2026-09-14 —— 复审修复 r2（对 r1 build 的 7 条 MAJOR；MINOR/NOTE 未动）
两段完成：**上一 agent**（被判停摆前）已把 7 条全部写进源码并起过一次通过的 build（日志已改名保留为 `docs/build_logs/build_2026-09-13_manual_dims_r2a.log`，mechanical_audit PASS，EXIT=2 = B01 预期）；**本 agent** 核对该 build 早于最后一次源码改动（源码 04:59:36 < 起建 ~05:05）后没有重建，只跑三只读检查 + 复审同款复量，复量发现 M6 仍有一处角点接触（下），补一刀后重建 = `docs/build_logs/build_2026-09-13_manual_dims_r2.log`（最终，07:29→07:35；18 件洞边 0 实体 1、静态 0、扫掠 264 个相交对/姿态、旧检查域 0、mechanical_audit PASS、EXIT=2 = B01 预期）；三只读检查 + 7 条复量：`docs/build_logs/checks_2026-09-13_manual_dims_r2.log`（复量脚本 `measure_r2.py` 正文附在末尾）。
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

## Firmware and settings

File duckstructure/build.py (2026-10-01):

#!/usr/bin/env python3
"""入口：./.venv/bin/python -m duckstructure.build（在仓库根目录跑）。
等价于原 tools/cad/duck.py 的 __main__：导出 17 个 STL 到 cad/duck_s288/、跑零位/扫掠/装配/机械检查、
写 audit_summary.json 与 mechanical_audit.json；有干涉或未闭环接口时退出码 2。"""
import os, sys, json, time as _time, numpy as np, trimesh
_T0 = _time.time(); _TL = [_T0]
def _tick(label):
    """hr42：阶段计时打印（只打印到日志，不改任何产物/判据）。"""
    now = _time.time(); print(f"[hr42计时] {label} {now - _TL[0]:.2f}s 累计 {now - _T0:.1f}s", flush=True); _TL[0] = now
import duckstructure as D          # 传给 assembly_audit / mechanical_audit 的"duck 模块"（原来是 sys.modules[__name__]）
from duckstructure import s288, K
from duckstructure.s288 import bx, placed
from duckstructure.lib import P, B, ORDER, OUT, BX0, BX1, BZ0, BZ1, TW, sfw, hull, keep_main, wbox, mirror_y, MIRROR, battery_box
from duckstructure.lib import clean_print_topology
from duckstructure.stamps import stamp
from duckstructure import wire_fixings as _WF          # hr44：线束固定点
CLEAN_AFTER_STAMP = {"L01", "L02", "L03", "L04", "L05", "L06", "L07", "L10", "L13", "H03", "H05"}   # builder 里已做规范化的件
from duckstructure.legs import build_yaw2roll, build_hip, build_upper_leg, build_lower_leg, build_ankle_foot, build_ankle_rear_arm
from duckstructure.trunk import build_trunk, build_battery_door, build_trunk_shell
from duckstructure.head import adapter_box, build_face_plate
from duckstructure.head_top import build_head_top_shell                           # hr38：H05 上头壳（原版 top_head_shell 派生件）
from duckstructure import jaw as JAW                                              # hr38：嘴关节（第 15 颗 S288 + J01 + 6700ZZ）
from duckstructure.electronics import ELECTRONICS                                    # hr37：电子件占位实体                                          # hr28：转接板占位改在头里（tail.py 的托架版作废）
from duckstructure.neck import build_neck, build_neck_pitch, build_yrm, build_head_journal
from duckstructure.head import build_head_bracket, build_head_clamp, build_head_bottom_shell
from duckstructure.hip_pitch_bearing_rebuild import build_hip_pitch_sleeve
from duckstructure.head_bearing_rebuild import build_head_roll_adapter, build_head_yaw_adapter, build_head_bearing_cap, build_head_yaw_cap
from duckstructure.checks import EXPORT_STATS, export, vol, run_checks
from duckstructure.bearing_rebuild import build_hip_roll_sleeve

if __name__ == "__main__":
    # hr42（2026-09-24）：件生成改成"先声明、再按内容哈希增量 + 分组并行、最后按原顺序逐件导出"（duckstructure/build_fast.py:BuildPlan）。
    #   声明顺序 / 刻字 / 规范化 / 镜像 / 占位 / 导出与原来逐行对应，产出 STL 与 placed/ 逐字节相同（hr42 对账）；
    #   新加件：add(体, 件名, **生成函数本身（不带括号）**, 文件名)；不在 build_fast.GROUPS 里的件自动归 misc 组。
    #   --no-build-cache（或 DUCK_BUILD_CACHE=0）= 全部现切；--build-jobs N（或 DUCK_BUILD_JOBS，默认 3）= 并行工作进程数。
    #   --no-check-cache（或 DUCK_CHECK_CACHE=0）= run_checks / verify_mechanics 的检查原语缓存不读不写（tools/cad/check_cache.py）。
    #   打印 / 交付 / 复审前：python -m duckstructure.build --no-build-cache --no-check-cache（全量实跑，那份才是放行依据）。
    if "--no-check-cache" in sys.argv:
        os.environ["DUCK_CHECK_CACHE"] = "0"
    from duckstructure.build_fast import BuildPlan, mirror_extras, export_extras   # hr46：附属实体（钩）
    from duckstructure.tail import build_battery_lid          # 下面声明段里要用的模块都在装记录器的"生成期"之前 import 完：
    from duckstructure import eye as EYE                      # 模块体在 import 期执行，只按它们被谁用到进依赖，不算进每个组
    PLAN = BuildPlan()
    parts = []     # (body, name, world mesh)
    _tick("import 完成")
    steps = []
    def add(body, name, thunk, fname=None):
        steps.append(("add", body, name, thunk, fname))
    def extra(body, name, thunk):                     # 只参与检查的占位（主进程现算，便宜；工作进程跳过）
        steps.append(("extra", body, name, thunk, None))
    add("yaw2roll", "yaw2roll", build_yaw2roll, "L01_yaw2roll.stl")
    add("hip_l", "hip", build_hip, "L02_hip.stl")
    add("upper_leg_left", "upper_leg", build_upper_leg, "L03_upper_leg.stl")
    add("leg", "lower_leg", build_lower_leg, "L04_lower_leg.stl")
    _af = {}
    def _ankle(which):                                # 原 af, sole = build_ankle_foot()：一次调用出两件
        if not _af: _af["af"], _af["sole"] = build_ankle_foot()
        return _af[which]
    add("ankle_left", "ankle_foot", lambda: _ankle("af"), "L05_ankle_foot.stl"); add("ankle_left", "sole", lambda: _ankle("sole"), "L06_sole_TPU.stl")
    add("ankle_left", "ankle_rear_arm", build_ankle_rear_arm, "L07_ankle_rear_arm.stl")
    add("hip_l", "hip_roll_sleeve", build_hip_roll_sleeve, "L10_hip_roll_sleeve.stl")
    add("hip_l", "hip_pitch_sleeve", build_hip_pitch_sleeve, "L13_hip_pitch_sleeve.stl")
    steps.append(("mirror", None, None, None, None))  # 原：for body, name, m in list(parts): parts.append((MIRROR[body], name + "_R", mirror_y(m)))
    _tr = {}
    def _trunk():                                     # 原 tr = build_trunk()：T01 与两片壳共用同一个原坯（刻字前）
        if "m" not in _tr: _tr["m"] = build_trunk()
        return _tr["m"]
    add("trunk_base", "trunk", _trunk, "T01_trunk.stl")
    add("trunk_base", "battery_door", build_battery_door, "B01_battery_door.stl")
    # hr28（09-21 用户定）：B02 尾部托架作废 —— 转接板进头里 Radxa 排针口袋下段（head.H03_ADP_*），像原版 HAT 一样随头走；占位挂 jaw_soft
    extra("jaw_soft", "zz_adapter", adapter_box)                                                    # 转接板占位 40×30×9，只参与检查
    # 电池实体也参加检查（BAT_CLR 已经含在仓腔里，这里放的是电池本体尺寸）
    extra("trunk_base", "zz_battery", battery_box)          # hr48：占位体尺寸/站位统一取 lib.battery_box()（20 厚电池、x 在 BX0_BAT..BX1 居中）
    add("trunk_base", "shell_L", lambda: build_trunk_shell(1, _trunk()), "T02_shell_L.stl")
    add("trunk_base", "shell_R", lambda: build_trunk_shell(-1, _trunk()), "T03_shell_R.stl")
    from duckstructure.tail import build_battery_lid                                            # hr39f：方案 (f) 电池顶盖（取消总开关，开盖拔 XT30 断电）
    add("trunk_base", "battery_lid", build_battery_lid, "B03_battery_lid.stl")
    add("neck", "neck", build_neck, "N01_neck.stl")
    add("neck_pitch", "neck_pitch", build_neck_pitch, "N02_neck_pitch.stl")
    add("yaw_roll_motion", "yrm", build_yrm, "N03_yaw_roll.stl")
    add("yaw_roll_motion", "head_journal", build_head_journal, "N04_head_journal.stl")   # 头横滚 B 端轴颈销（09-12 ④）
    add("yaw_roll_motion", "head_roll_adapter", build_head_roll_adapter, "N05_head_roll_adapter.stl")
    add("neck_pitch", "head_yaw_adapter", build_head_yaw_adapter, "N06_head_yaw_adapter.stl")
    add("yaw_roll_motion", "head_bearing_cap", build_head_bearing_cap, "N07_head_bearing_cap.stl")
    add("yaw_roll_motion", "head_yaw_cap", build_head_yaw_cap, "N08_head_yaw_cap.stl")
    add("jaw_soft", "head_bracket", build_head_bracket, "H01_head_bracket.stl")
    add("jaw_soft", "head_clamp", build_head_clamp, "H02_head_clamp.stl")
    add("jaw_soft", "head_bottom_shell", build_head_bottom_shell, "H03_head_bottom_shell.stl")
    add("jaw_soft", "face_plate", build_face_plate, "H04_face_plate.stl")                      # hr37：脸板（替换原版 face_part）
    add("jaw_soft", "head_top_shell", build_head_top_shell, "H05_head_top_shell.stl")          # hr38：上头壳派生件（通风槽/声孔/喇叭卡座/功放卡座），取代 placed/ 里的 orig_top_head_shell
    add("jaw_soft", "jaw", JAW.build_jaw, "J01_jaw.stl")                                       # hr38：活动嘴；hr41：v2（最后从下装，两毂各 3 颗 M2 沉头）
    add("jaw_soft", "jaw_adapter", JAW.build_jaw_adapter, "J02_jaw_adapter.stl")               # hr41：+y 舵机法兰转接盘（一次装好不拆）
    add("jaw_soft", "jaw_journal", JAW.build_jaw_journal, "J03_jaw_journal.stl")               # hr41：−y 可拆轴颈盘（进 6700 内圈）
    from duckstructure.head import build_camera_clamp
    add("jaw_soft", "camera_clamp", build_camera_clamp, "H06_camera_clamp.stl")                # hr41：摄像头内侧压框（PCB 贴 H04 内面）
    # was_until_2026_09_25_hr43d: from duckstructure.head import build_amp_tray
    # was_until_2026_09_25_hr43d: add("jaw_soft", "amp_tray", build_amp_tray, "H07_amp_tray.stl")                            # hr43：功放托板（直排针功放；3×M2×8 拧 H01 旧 Radxa 立柱端面，F35）
    from duckstructure.head import build_adapter_tray, build_amp_bracket
    add("jaw_soft", "adapter_tray", build_adapter_tray, "H08_adapter_tray.stl")                # hr43d：转接板托板（B′，取代 H07；3×M2×8 拧 H01 旧 Radxa 立柱端面，F35；板泡棉胶 + 2 扎带）
    add("jaw_soft", "amp_bracket", build_amp_bracket, "H09_amp_bracket.stl")                  # hr43d：功放支架（E′，后脑 +y；F38 2×M2×6 拧 H03 凸台，功放 F36 2×M2×5）
    from duckstructure.head import build_tof_clamp
    add("jaw_soft", "tof_clamp", build_tof_clamp, "H10_tof_clamp.stl")                          # hr52：ToF 压条（v6-VL53L5CX 雷达；2×M2×6 从背面拧进 H04 两根柱）
    from duckstructure import eye as EYE                                                          # hr39c：圆眼装饰三件（白外圈 / 黑眼珠 / 高光点，每件单色，粘在 H04 前面）
    for _pid, (_fname, _nm, _fn) in EYE.PARTS.items():
        add("jaw_soft", _nm, _fn, _fname)
    # ── 执行：主进程先按组键判命中、未命中的组起工作进程并行现切；然后按上面的声明顺序逐件取回、导出（工作进程只现切本组件，存 npz 后退出）
    if not PLAN.worker:
        PLAN.prepare([(b, n, f, f[:3] in CLEAN_AFTER_STAMP) for k, b, n, t, f in steps if k == "add" and f])
        _tick("生成（分组工作进程 / 缓存读回）")
    for kind, body, name, thunk, fname in steps:
        if kind == "mirror":
            if PLAN.worker: continue
            for b_, n_, m_ in list(parts):
                parts.append((MIRROR[b_], n_ + "_R", mirror_y(m_)))
                mirror_extras(n_, n_ + "_R", mirror_y)          # hr46：镜像件的附属实体还没做，左件有就报错
            _tick("镜像右腿")
            continue
        if kind == "extra":
            if not PLAN.worker: parts.append((body, name, thunk()))
            continue
        if PLAN.worker:
            if fname and PLAN.wants(name):
                # hr15：每个打印件刻件号（stamps.STAMPS 世界系位置；小回转件点码）。刻在 builder 之后、镜像/审计/导出之前，
                # 这样右腿镜像件、placed/ 与所有审计看到的都是刻过字的几何。原来过了 clean_print_topology 的件刻完再过一遍。
                m = thunk() if callable(thunk) else thunk
                m = _WF.apply(fname[:3], m)                   # hr44：线束固定点（两孔扎带位 / 扎带桥，duckstructure.wire_fixings），刻字前
                m = stamp(m, fname[:3])
                if fname[:3] in CLEAN_AFTER_STAMP: m = clean_print_topology(m)
                PLAN.produce(name, body, fname, m, fname[:3] in CLEAN_AFTER_STAMP)
            continue
        m = PLAN.mesh(name) if fname else (thunk() if callable(thunk) else thunk)
        parts.append((body, name, m))
        if fname: export(m, fname, body)
        _tick(f"刻字/导出 {name}")
    PLAN.end_of_parts()                               # 工作进程：记依赖、存结果、在这里退出
    _tick("圆眼")
    for body, name, fn in ELECTRONICS: parts.append((body, name, fn()))                          # hr37：zz_sbc/mic/camera/imu/ubec…；hr39f：开关删除，+ zz_xt30（电池顶对插头+平衡头）
    # hr38：头部三个原版件全部由派生件取代，placed/ 里不再有 orig_*
    #   face_part → H04（hr37）、top_head_shell → H05（hr38）、jaw → J01（hr38）。原版 STL 仍是毛坯与合缝基准（frozen.yaml sha256 不变）。
    _tick("电子件占位")
    # 诊断：横滚舵机背后到底壳内壁的距离
    probe = wbox((-34, -25, 224), (-19.4, 10, 247))
    for p in B["jaw_soft"]["parts"]:
        if p["mesh"] in ("top_head_shell", "bottom_head_shell"):
            m = K.mesh(p["mesh"]); m.apply_transform(TW("jaw_soft") @ p["T"]); v, it = vol(probe, m)
            print(f"  [诊断] {p['mesh']} 在横滚舵机背后区域的材料: {v/1000:.2f} cm³ x∈{np.round(it.bounds[:,0],1) if it is not None else '-'}")
    # 舵机占位
    servos = []
    for n in ORDER:
        for i, s in enumerate(B[n]["servos"]):
            if s["drives"] is None: continue          # 下颚舵机 V1 不装
            R = sfw(n, i)
            servos.append((n, f"servo_{n}_{s['drives'].replace(':self','')}", placed(s288.servo_mesh(), R)))
    # hr38：第 15 颗 = 嘴舵机。MJCF robot_walk.xml 里下颚不是关节 → kin.load() 给它 drives=None（上面的循环跳过），位姿由 jaw.servo_R() 自己定（法兰 +y、顶端 −x）
    servos.append(("jaw_soft", "servo_jaw_soft_jaw", JAW.servo_mesh_world()))
    # 金属轴承必须参加整机多关节检查；不能只量座孔而漏掉完整实体。
    from assembly_audit import bearing_specs
    bearings = []
    for spec in bearing_specs(D):
        raw = spec["shape"].to_mesh64()
        mesh = trimesh.Trimesh(vertices=np.asarray(raw.vert_properties)[:, :3],
                               faces=np.asarray(raw.tri_verts), process=False)
        bearings.append((spec["mount"], "bearing_" + spec["name"], mesh))   # mount = 外圈压在哪个连杆里（bearing_specs 里逐颗写明）
    bearings.append(("jaw_soft", "bearing_jaw", JAW.bearing_mesh_world()))   # hr38：嘴惰轮侧 6700ZZ（外圈在 H01 上半拱 + H03 下半环拼的 Ø15.1 座）
    allm = parts + servos + bearings
    _tick("诊断+舵机/轴承占位")
    xxd = os.path.join(OUT, "xx"); os.makedirs(xxd, exist_ok=True)
    for f in os.listdir(xxd): os.remove(os.path.join(xxd, f))
    checks = run_checks(allm, export_intersections=True)
    _tick("run_checks")
    checks["stl"] = EXPORT_STATS
    with open(os.path.join(OUT, "audit_summary.json"), "w") as f:
        json.dump(checks, f, ensure_ascii=False, indent=2)
    from mechanical_audit import verify_mechanics
    import check_cache as _CC; _CC.set_context("verify_mechanics")       # hr42：未命中日志的"在算谁"（run_checks 里逐对设过，这里换成整段标签）
    mechanics = verify_mechanics(D, allm)
    _tick("verify_mechanics")
    with open(os.path.join(OUT, "mechanical_audit.json"), "w") as f:
        json.dump(mechanics, f, ensure_ascii=False, indent=2)
    # 局部视图：每个打印件 + 它周围的舵机，按世界坐标（看图方便）
    ld = os.path.join(OUT, "local"); os.makedirs(ld, exist_ok=True)
    import shutil
    for f in os.listdir(ld): shutil.rmtree(os.path.join(ld, f))
    for (b, nm, m) in parts:
        if nm.endswith("_R") or nm.startswith("orig_"): continue
        d = os.path.join(ld, nm); os.makedirs(d, exist_ok=True); keep_main(m, nm).export(os.path.join(d, "part.stl"))
        for (sb, snm, sm) in servos:
            v, it = vol(sm, hull(m, m))          # 舵机与该件凸包相交 → 相关舵机
            if v > 50: sm.export(os.path.join(d, snm.replace("servo_", "servo__") + ".stl"))
        if nm == "head_bracket":
            for (sb, snm, sm) in parts:
                if snm.startswith("orig_bottom"): sm.export(os.path.join(d, "orig_bottom.stl"))
    _tick("local/ 局部视图")
    # 两套渲染场景：scene_shell（装上原版躯干壳/头壳 = 完整鸭子）、scene_skeleton（剥掉所有壳 = 骨架）
    SHELLS = ("head_top_shell", "head_bottom_shell", "jaw", "jaw_adapter", "jaw_journal", "face_plate", "shell_L", "shell_R", "battery_lid", "eye_white", "eye_pupil", "eye_highlight")   # hr38：顶壳→H05、嘴→J01；hr39c：+ 圆眼三件；hr39f：+ B03 顶盖（壳的一块）；hr41：+ J02/J03（外露的盘）
    batm = battery_box()
    for scn, with_shell in (("scene_shell", True), ("scene_skeleton", False)):
        sd = os.path.join(OUT, scn); os.makedirs(sd, exist_ok=True)
        for f in os.listdir(sd): os.remove(os.path.join(sd, f))
        for (b, nm, m) in allm:
            if not with_shell and nm in SHELLS: continue
            keep_main(m, nm).export(os.path.join(sd, (nm if not nm.startswith("servo") else nm.replace("servo_", "servo__")) + ".stl"))
        batm.export(os.path.join(sd, "zzbattery.stl"))
    _tick("scene_shell/scene_skeleton")
    sc = trimesh.util.concatenate([m for (_, _, m) in allm]); sc.export(os.path.join(OUT, "assembly_preview.stl"))
    _tick("assembly_preview")
    pd = os.path.join(OUT, "placed"); os.makedirs(pd, exist_ok=True)
    for f in os.listdir(pd): os.remove(os.path.join(pd, f))
    for (b, nm, m) in allm: keep_main(m, nm).export(os.path.join(pd, (nm if not nm.startswith("servo") else nm.replace("servo_", "servo__")) + ".stl"))
    # hr46（2026-09-26）：件的附属实体（线束钩 / 卡槽；件的生成函数里 build_fast.produce_extra 登记）→ hooks/<件号>_<锚点id>.stl。
    #   与主网格同一条缓存记录（命中读回、未命中工作进程产出），增量与无缓存 build 逐字节相同；第 6 层只读这些文件。全量 build 整目录重建。
    _hooks = export_extras([n for k, b, n, t, f in steps if k == "add" and f], PLAN.fname_of, clear_all=True)
    _tick(f"hooks/（{len(_hooks)} 个附属实体）")
    # 2026-09-22 快车道缓存：把每个打印件（含镜像件）**布尔后、keep_main 前**的世界系网格原样存起来，build_fast.py 只重切改动件、其余从这里读回
    # （placed/ 的 STL 经 float32 + 顶点合并后 L05 不再是 volume，布尔会拒；npz 是精确的内存几何）。manifest 记该件导出 STL 的 sha，读回前核对。
    from duckstructure.build_fast import write_cache
    _tick("placed/")
    write_cache(parts, plan=PLAN)                     # hr42：件条目带组键 / 网格摘要，清单顶层带 __hr42_groups__（下次全量 build 增量用）
    import shutil as _sh
    _sh.rmtree(os.path.join(OUT, "cache", "hr42_workers"), ignore_errors=True)
    with open(os.path.join(OUT, "cache", "hr42_build_report.json"), "w") as f:
        json.dump(PLAN.summary(), f, ensure_ascii=False, indent=1)
    print("[增量] " + json.dumps(PLAN.summary(), ensure_ascii=False))
    _tick("快车道缓存")
    print("assembly bbox", np.round(sc.bounds, 1).tolist())
    try:                                                     # hr44：线束（头内 + 头外）实体导出到 placed 旁 wires/ + 头外粗扫掠摘要（只报告，不改退出码）
        from duckstructure import wiring_body as _WB
        print(_WB.export_all(os.path.join(OUT, "wires")), flush=True)
    except Exception as _e:                                  # noqa: BLE001
        print(f"[线束] 导出 / 检查失败：{_e}", flush=True)
    # 生成产物完成后再给失败退出码，避免检查有真碰撞却被脚本当成通过。
    if not checks["sampled_collision_free"] or not mechanics["passed"] or mechanics["unresolved"]:
        print("[未放行] STL 已生成，但整机仍有干涉或未闭环接口；退出码 2。")
        sys.exit(2)
    print("[采样检查通过] 仍需组合姿态、装配实物与打印公差验证。")

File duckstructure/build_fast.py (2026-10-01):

#!/usr/bin/env python3
"""快车道（2026-09-22）：只重切 --only 里的件，其余打印件从缓存读回，然后跑与 duckstructure.build **相同**的 run_checks + verify_mechanics，
写 audit_summary.json / mechanical_audit.json，导出 STL + placed/ 只写重切的件（含镜像件）。跳过 local/ scene_*/ assembly_preview。

    ./.venv/bin/python -B -m duckstructure.build_fast --only H03[,N02,...]        # 件号前缀（文件名前 3 位）

读回优先级：cad/duck_s288/cache/<name>.npz（manifest 里该件导出 STL 的 sha 与现在相同）→ placed/<name>.stl（trimesh 合并顶点后必须是 volume）→ 都不行就重切。
缓存由 build.py（全量）与本脚本（重切的件）在每次 build 末尾写入，所以第一次全量 build 之后快车道才有缓存；没缓存时退化成从 placed/ 读（09-22 实测：
除 L05/L06 外读 placed/ 与内存几何跑出的 audit/placed 逐字节相同，L05 placed 不是 volume 会自动重切）。
快车道只用于迭代；交付/复审前、改 assembly 结构或 Gate 层代码时仍跑全链（hrNN_go.sh）。"""
import os, sys, json, time, hashlib, argparse, re
import numpy as np, trimesh

CACHE_DIRNAME = "cache"

def _cache_dir():
    from duckstructure.lib import OUT
    d = os.path.join(OUT, CACHE_DIRNAME); os.makedirs(d, exist_ok=True); return d

def _sha(path):
    return hashlib.sha256(open(path, "rb").read()).hexdigest() if os.path.exists(path) else None

# ── hr46：件的附属实体（钩）登记表与存读导出住在 duckstructure/build_extras.py（进程内唯一一份；本文件被当 __main__ 跑时也共用）──
from duckstructure.build_extras import (EXTRA_DIRNAME, _EXTRAS, produce_extra, extras_of, mirror_extras,   # noqa: E402,F401
                                        _save_extras, _load_extras, export_extras, mesh_digest)


def write_cache(parts, plan=None):
    """parts = [(body, name, world mesh)]；只存有导出文件的打印件及其 _R 镜像（orig_*/zz_* 每次现生成，便宜）。
    hr42：plan（build.py 的 BuildPlan）给出时，件条目另记 hr42_group / hr42_group_key / hr42_mesh_digest，清单顶层记 __hr42_groups__
    （全量 build 增量用）；快车道（plan=None）重写的件条目不带这些字段 → 下次全量 build 该组必然未命中、重切。"""
    from duckstructure.lib import OUT
    d = _cache_dir(); mpath = os.path.join(d, "manifest.json")
    man = json.load(open(mpath)) if os.path.exists(mpath) else {}
    per, groups = plan.manifest_extra() if plan is not None else ({}, None)
    for body, name, m in parts:
        if name.startswith(("orig_", "zz_")): continue
        base = name[:-2] if (name.endswith("_R") and name[:-2] in FNAME) else name   # shell_R 不是 shell 的镜像（hr33 复审 m-01）
        fname = FNAME.get(base)
        if not fname: continue
        np.savez(os.path.join(d, name + ".npz"), v=np.asarray(m.vertices, dtype=np.float64), f=np.asarray(m.faces, dtype=np.int64))
        ex = _save_extras(d, name, clean=True)          # hr46：附属实体（钩）存进同一条记录，清单记 {标签: 摘要}
        man[name] = dict(body=body, export=fname, export_sha256=_sha(os.path.join(OUT, fname)), hr42_extras=ex, **per.get(name, {}))
    if groups is not None:
        man["__hr42_groups__"] = groups
    json.dump(man, open(mpath, "w"), ensure_ascii=False, indent=1)

# 件名 → 导出文件（与 build.py 的 add(...) 一一对应；改 build.py 时同步）
FNAME = {"yaw2roll": "L01_yaw2roll.stl", "hip": "L02_hip.stl", "upper_leg": "L03_upper_leg.stl", "lower_leg": "L04_lower_leg.stl",
         "ankle_foot": "L05_ankle_foot.stl", "sole": "L06_sole_TPU.stl", "ankle_rear_arm": "L07_ankle_rear_arm.stl",
         "hip_roll_sleeve": "L10_hip_roll_sleeve.stl", "hip_pitch_sleeve": "L13_hip_pitch_sleeve.stl",
         "trunk": "T01_trunk.stl", "battery_door": "B01_battery_door.stl", "shell_L": "T02_shell_L.stl", "shell_R": "T03_shell_R.stl",
         "battery_lid": "B03_battery_lid.stl",          # hr39f
         "neck": "N01_neck.stl", "neck_pitch": "N02_neck_pitch.stl", "yrm": "N03_yaw_roll.stl", "head_journal": "N04_head_journal.stl",
         "head_roll_adapter": "N05_head_roll_adapter.stl", "head_yaw_adapter": "N06_head_yaw_adapter.stl",
         "head_bearing_cap": "N07_head_bearing_cap.stl", "head_yaw_cap": "N08_head_yaw_cap.stl",
         "head_bracket": "H01_head_bracket.stl", "head_clamp": "H02_head_clamp.stl", "head_bottom_shell": "H03_head_bottom_shell.stl",
         "face_plate": "H04_face_plate.stl",
         # hr39c：hr38 起 build.py 已有 H05/J01（快车道当时没跟上，这里补齐）+ 圆眼三件
         "head_top_shell": "H05_head_top_shell.stl", "jaw": "J01_jaw.stl",
         "eye_white": "E01_eye_white.stl", "eye_pupil": "E02_eye_pupil.stl", "eye_highlight": "E03_eye_highlight.stl",
         # hr41：嘴两转接盘 + 摄像头压框
         "jaw_adapter": "J02_jaw_adapter.stl", "jaw_journal": "J03_jaw_journal.stl", "camera_clamp": "H06_camera_clamp.stl",
         # hr43：功放托板（hr43d 退役，条目留痕：不再 add）
         "amp_tray": "H07_amp_tray.stl",
         # hr43d：转接板托板（取代 H07）+ 功放支架（后脑 +y）
         "adapter_tray": "H08_adapter_tray.stl", "amp_bracket": "H09_amp_bracket.stl",
         # hr52：ToF 压条（v6-VL53L5CX 雷达）
         "tof_clamp": "H10_tof_clamp.stl"}

def _load_cached(name, fname):
    """返回 (world mesh, 来源) 或 (None, 原因)。"""
    from duckstructure.lib import OUT
    d = _cache_dir(); mpath = os.path.join(d, "manifest.json"); npz = os.path.join(d, name + ".npz")
    man = json.load(open(mpath)) if os.path.exists(mpath) else {}
    cur = _sha(os.path.join(OUT, fname))
    if name in man and os.path.exists(npz) and man[name].get("export_sha256") == cur and cur is not None:
        err = _load_extras(d, name, man[name].get("hr42_extras") or {})   # hr46：附属实体一起读回；缺 / 摘要不符 → 不用缓存，重切
        if err: return None, err
        z = np.load(npz); return trimesh.Trimesh(vertices=z["v"], faces=z["f"], process=False), "cache"
    pl = os.path.join(OUT, "placed", name + ".stl")
    if os.path.exists(pl):
        m = trimesh.load(pl, force="mesh")            # 默认 merge_vertices；不合并的话每条边都是洞边，is_volume=False
        if m.is_volume: return m, "placed"
        return None, "placed 不是 volume"
    return None, "无缓存无 placed"
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

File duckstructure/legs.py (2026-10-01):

"""腿（左）L01–L07：髋偏航-横滚件 / 髋件 / 大腿 / 小腿 / 踝主脚+鞋底 / 踝后臂。右腿由 build.py 镜像。"""
import math, numpy as np
from .s288 import S, cyl, bx, union, diff, inter, placed
from . import hip_pitch_bearing_rebuild as HPR
from .bearing_rebuild import (HR, hip_roll_seat_local, hip_roll_seat_cut_local, hip_roll_module_local,
                              hip_roll_driven_local, hip_roll_sleeve_local, hip_roll_old_clearance_local)
from .lib import (P, RINGS, BX0, BX1, BZ0, BZ1, BX0_BAT, ANK_J, ANK_COL, ANK_SWEEP_LO, ANK_SWEEP_HI, ANK_SWEEP_N_LEG, ANK_SWEEP_N_SERVO, conn_hump_sweep,
                  KNEE_CUT_HI, KNEE_HEEL_LO, KNEE_HEEL_HI, KNEE_HEEL_N, KNEE_L03_LO, KNEE_L03_HI, KNEE_L03_N, ANK_X0, ANK_X1b, ANK_X1, X_ENV_BOSS, x_bshell_out, XR,
                  memo, orig, sfw, drv_from, drv_self, pt, servo_env, driven, keep_main, servo_slide, bearing_driven_clearance,
                  clean_print_topology, fill_cyl, driven_patch, horn_cbore, flange_relief, horn_cut, silhouette, back_shell,
                  ring_boss, sweep_of, mnt_cut2, mirror_y, conn_cut, back_pad, seat_ring_clearance, seat_ring_zone, wbox, BAT_Y, region_cut, minkowski_box)

# ── 2026-09-17 真实姿态缺陷区域刀（lib.region_cut；数据 duckstructure/data/regions_2026-09-17/，来自 r4 的 policy_pose_compare 10 个缺陷对）──
# 双腿联动/头缩姿态，单关节 sweep 表达不了；每对只切**一侧**：切运动件/远端件，不切原版冻结件与舵机。右件区域镜像到左件，左右同刀。
# L02：L02×L02（roulade 7 姿态，两侧各 5–6 mm³）、L02×原版 jaw（4，14）、L02×T01（1+2，3+2）；L04：L04 踝端外侧 vs L02（6，53）、L04×原版上头壳（1，2）；L07：后臂顶边 vs L02（3，8.5）
# was_until_2026_09_28_hr50: HIP_REGION_CUTS = (("hip__pair_hip_l_x_hip_l_2.stl", "hip_l", False), ("hip_R__pair_hip_l_x_hip_l_2.stl", "hip_l_2", True),
# was_until_2026_09_28_hr50:                    ("hip_R__pair_hip_l_2_x_jaw_soft.stl", "hip_l_2", True), ("hip_R__pair_hip_l_2_x_trunk_base.stl", "hip_l_2", True),
# was_until_2026_09_28_hr50:                    ("hip__pair_hip_l_x_trunk_base.stl", "hip_l", False))
# was_until_2026_09_28_hr50: LOWER_LEG_REGION_CUTS = (("lower_leg_R__pair_hip_l_2_x_leg_2.stl", "leg_2", True), ("lower_leg_R__pair_jaw_soft_x_leg_2.stl", "leg_2", True))
# was_until_2026_09_28_hr50: REAR_ARM_REGION_CUTS = (("ankle_rear_arm_R__pair_ankle_right_x_hip_l_2.stl", "ankle_right", True),)
# hr50（2026-09-28 主设计逐刀决定，依据 hr50_work/poses/region_recheck.md：当前几何复算 + 算法会话 C 中档 ≤2.29 mm³ 且 ≤0.77 mm）——三组区域刀全部撤掉：
#   L02#7 / #12（右 / 左 L02 顶角 × 躯干底边）：轻碰，交集 ≤1.0 / 0.9 mm³、穿深 ≤0.45 / 0.53，在中档内，原版同姿态也撞；
#   L02#9 / #10（两个 L02 翻滚动作髋偏航到头互擦）：穿深 ≤0.53，原版 5/7 也撞，且这两刀咬 L02 沉窝（用户规矩：沉窝不许咬）；
#   L02#8（新头 × 右 L02）：交集最大 504 mm³、刀只削得到 17.5，带刀后 48 姿态照撞 → 刀没用，交关节限位 / 训练；
#   L04#12（新头 × 小腿）：280 mm³ 深 6.2、刀只削 5.8，没用且咬螺丝孔；L04#9（深蹲极限小腿踝端 × L02）：带刀后 4 姿态仍 ≤103 mm³，交限位；
#   L07#7 / L05#11（后臂顶边 × 右 L02）：带刀后 11 姿态照撞，没用。区域刀用 minkowski_box 外扩 0.4，本身就是碎边来源（B 表 L02/L04 碎边×7）。
HIP_REGION_CUTS = ()
LOWER_LEG_REGION_CUTS = ()
REAR_ARM_REGION_CUTS = ()

# ───────────────────────────── 腿（左）——全部世界坐标 ─────────────────────────────
HIP_ROLL_DISC_D = 20.0   # 09-17：髋横滚从动盘 Ø（旧 26，随 6704 一起取消；r 10 → 零位离中线 7.5，与原版 hip_l 的 8.0 同级；试算 0/77 姿态相交，见 lib.RINGS 注释）
L01_SEAT = 19.2      # L01 偏航盘 6 颗 M2 的坐面（髋偏航舵机局部 x）= 原版杯壁外表面 = 横滚舵机顶端(世界 z 112.0)+CLR → 131.5−112.3；只与 top/CLR/舵机位姿有关，不随 T/flange_h 变
# 09-14 复审 BLOCKER：旧坐面 = 法兰面 13.0 + 5.35 = 18.35，头 Ø4×1.6 顶到 19.95 > 杯壁外面 19.2 = 横滚舵机顶端(19.5)−CLR，
# 12 颗头全部压进横滚舵机顶端 0.45（每颗 ∩ 5.646 mm³；旧 12.85 法兰面时已压 0.30）。旧检查只查头 vs L01 自身，没查头 vs 横滚舵机。
# 改：叠厚 5.35 → 4.0（沉窝深 0.85 → 2.2，坐面 17.0 = 毂 13.0..17.5 内、6702 内圈区 13..17 之外），头顶 18.6 ≤ 19.2（离横滚舵机顶 0.9），
# F02 改 M2×6（咬 2.0；长度规则 6 ≤ 4.0+3.0−0.3 ✓）。沉窝 Ø4.4 外缘 r 7.45 只在 x 17.0..17.5 破毂外圆 Ø14.85 0.025（座环让位带内，无功能）。
L01_STACK = 4.0      # 6 颗 M2×6 的叠厚（F02，mechanical_audit hip_yaw L01 screw seats 按它判）：沉窝深 = L01_SEAT − (法兰面 + 4.0) = 2.2（旧 5.35/M2×8/沉 0.85）
L01_SCREW_L = 6.0    # F02 螺丝长（mechanical_audit 咬入 = L01_SCREW_L − 叠厚 = 2.0；旧 8）
ANK_SIL_R = 13.0     # L04 踝端背板的投影轮廓圆半径（silhouette extra_circles，Ø26）
@memo
def build_yaw2roll():
    """髋偏航-横滚件（照原版 yaw2roll.stl 重雕）。原版是个小杯子：一头是偏航从动盘，一头包住横滚舵机的顶半段。
    原版只用了横滚舵机背面**上排**那 2 个孔（实测 Ø4.84 沉孔在世界 (-8.2, 9.5/25.5, 110)，正是 (±8, z=+7.5)），
    下排孔在原版件之外，我们照搬这个 2 螺丝方案。
    偏航端（RINGS["left_hip_yaw"]）：法兰侧 6702 副支撑（原版此处本来就有一颗 22×16×4（舵盘面平面，受力报告 §4 判为推力式夹持），S288 法兰配不了那种夹法，我们改法兰侧径向 6702）（理由见 lib.P["brg_yaw"] / trunk.build_trunk）：
    本件出 Ø14.85 毂（x 13.0..17.5）套 6702 内圈，Ø26 盘退到 17.5..20.5（被横滚舵机包络削到 L01_SEAT=19.2，和以前一样），
    6 颗 M2×6 叠厚 L01_STACK=4.0（19.2−13.0=6.2 沉 2.2；09-14 复审前 5.35/M2×8/沉 0.85，头顶 19.95 穿横滚舵机顶端 19.5——见 L01_STACK 注释）、咬 2.0；
    原版杯顶的 Ø16 盘和两片 XL330 耳朵在座环带（z 114.0..118.7, r 7.4..12.6）被 seat_ring_clearance 切掉。"""
    Rp = drv_from("yaw2roll")                          # 躯干里的髋偏航舵机，法兰朝下
    Rs = sfw("yaw2roll", 0)                            # 髋横滚舵机，法兰朝 +x
    O = orig("yaw2roll", "yaw2roll")
    dr, dh, xe, xi = driven(ring=RINGS["left_hip_yaw"], d=26.0, cbore=True, brg=P["brg_yaw"])
    cs = pt(Rs, 0)
    sil = silhouette(O, 1, pad=0.5, span=(4.0, 32.0), extra_circles=[(cs[0], cs[2], 14.0)])
    add = [placed(dr, Rp), inter(back_shell(Rs, 3.0), sil)]
    if not RINGS["left_hip_yaw"]: add.append(driven_patch(Rp, 26.0))     # 有毂时毂就是贴合面，不再补 1.65 那片
    xf = S["T"] / 2 + S["flange_h"]
    cuts = [horn_cut(Rp), horn_cbore(Rp, L01_SEAT, L01_SEAT - (xf + L01_STACK)),   # 杯壁外表面 19.2（横滚舵机顶端 112.0+CLR，不随 T 变）沉到叠厚 4.0：沉 2.2（09-14；旧 0.85→头穿横滚舵机顶），M2×6 咬 2.0
            servo_env(Rs), servo_env(Rp), flange_relief(Rp),
            mnt_cut2(Rs, pairs=(0,), cb_x0=-14.5, cb_d=x_bshell_out(3.0) - (-14.5))]   # 只用上排 2 孔；沉到背板外表面 -13.3（沉 1.2；旧 1.25 → -13.25）→ 叠厚 3.3，M2×6 咬 2.7
    # hr11：髋偏航舵盘 6 颗 M2 的起子通道（Ø4.2，从叠厚顶 xf+L01_STACK 沿 +x 30；mechanical_audit hip_yaw L01 head/tool envelope 同款刀）——
    #        hr08 整体座并入后 60°/120° 两条通道各被擦进 1.19 mm³（世界 z 111..114.5）
    cuts.append(placed(union(*[cyl(4.2, 30.0, (xf + L01_STACK + 15.0, S["horn_r"] * math.cos(a), S["horn_r"] * math.sin(a)), axis="x")
                               for a in np.linspace(0, 2 * math.pi, S["horn_n"], endpoint=False)]), Rp))
    if RINGS["left_hip_roll"]:
        add.append(placed(hip_roll_seat_local(), Rs))          # hr08：6703 整体座 + 顶桥/外侧桥并入本体
        cuts.append(placed(hip_roll_seat_cut_local(), Rs))     # 座孔/唇孔/开顶在并集之后切
        # 09-20 背插模型（lib.CONN_MODE "free"）：L01 背板到不了插座区，两个口都空着；这把刀只削掉板下角伸进
        # 线弯区的 0.3 mm³ + 侧出线区 2.9 mm³（hr15 探针），两侧都出。旧 hr06 "−y 走廊被挡 64 mm³ / 只开总线侧"是侧插模型的事，作废。
        cuts.append(conn_cut(Rs, sides=(1, -1), mode="pocket"))
    # hr10：L02 上 F06 六颗螺丝头（坐面 horn_seat 起 1.6 高，露出盘面 0.6）一起做 L01 的让位扫掠——hr09 运动审计 yaw2roll×F06_heads 72/278 姿态 6.2 mm³
    f06_heads = placed(union(*[cyl(P["m2_head_d"], P["m2_head_h"], (HPR.HP["horn_seat"] + P["m2_head_h"] / 2, S["horn_r"] * math.cos(a), S["horn_r"] * math.sin(a)), axis="x")
                              for a in np.linspace(0, 2 * math.pi, S["horn_n"], endpoint=False)]), drv_self("upper_leg_left"))
    # was_until_2026_09_28_hr50: cuts.append(sweep_of(union(build_hip(), f06_heads), "hip_l", -24, 24, 9, grow=0.4, mink=True))
    # hr50：6°/步在杯顶外沿留锯齿（clean_check 碎边 (12.9, 29.0, 115.2)）→ 33 步（1.5°/步），范围不变
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

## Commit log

2026-09-22 Initial: README (zh/en), licenses, notice
    设计阶段的项目说明与许可证，暂不含 CAD、STL 与数据。
    代码 Apache 2.0；硬件/3D 模型 CC BY-NC-SA 4.0（Pollen Microduck 衍生作品，非商用）。
2026-10-01 Gate: 8-layer check framework, design data and negatives
    [l1_calibration.yaml]
2026-10-01 tools: assembly/mechanical audits and simulation tooling
2026-10-01 duckstructure: parametric CAD generator with region meshes
    [ankle_rear_arm_R__pair_ankle_right_x_hip_l_2.stl, head_bottom_shell__pair_jaw_soft_x_neck.stl, hip_R__pair_ankle_right_x_hip_l_2.stl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]
